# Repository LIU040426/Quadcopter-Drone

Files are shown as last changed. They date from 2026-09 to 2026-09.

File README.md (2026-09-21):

# Quadcoater Drone

## Introduction

This is a Quadcoater Drone project.

## Hardware equipment

- F450 Framework
- Turnigy Liop Battery 3S
- SKYRC LiPro Balance Charger
- AMP 2.8.0 Fly Controller
- FS-i6 Fly remote controller
- DJI 2212/920KV brushless motor and ESC *4
- GPS module 
- Battery voltage module

## Supporting equipment
- Multimeter
- Soldering tools
- Screwdriver
- Hot glue gun
- Cable tie
- 

## Soldering the Battery and ESC

Before we start this project, we need soldering the the battery line and the
ESC line to the bottom board of the F450 frame. The after soldering picture is shown below:

<div align="center">
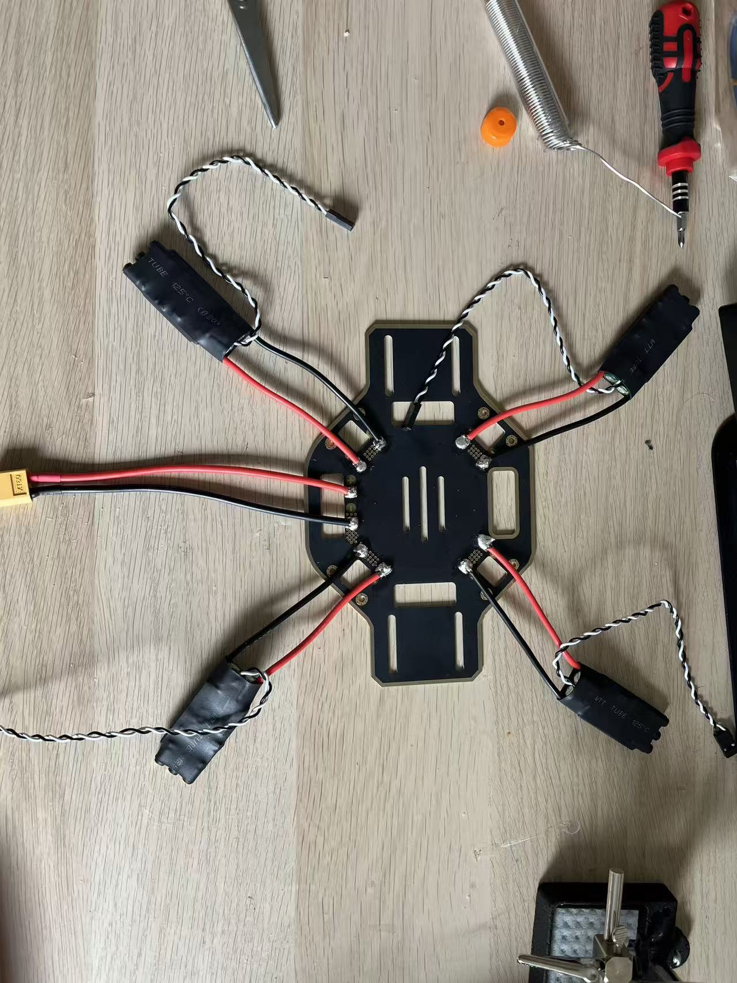
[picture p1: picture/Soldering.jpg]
  
</div>

Be Careful soldering each line in a correct pad. This F450 board has the + and - label to make sure it. After that, use the multimeter to test them.

After that, connect the battery to battery line and connect the ESC and brushless motor. It is shown below:

<div align="center">
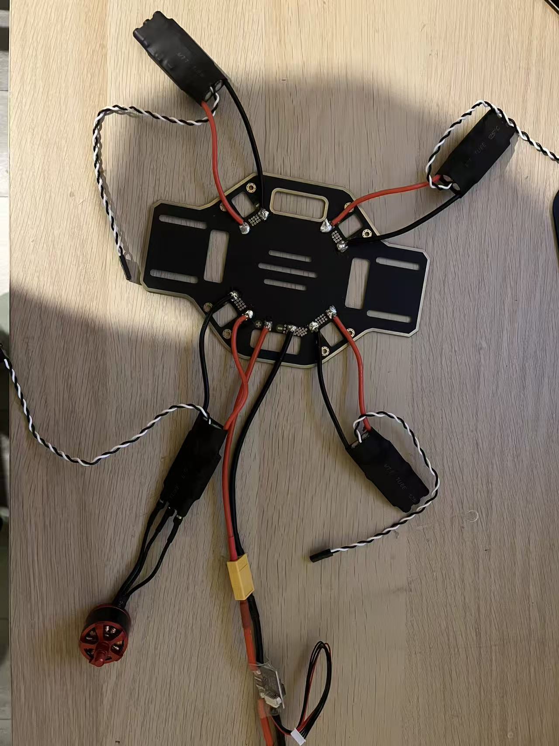
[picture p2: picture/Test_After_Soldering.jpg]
  
</div>

At this moment, the Motor will have some noise. BBBBBB...

It is normal, since the noise means the power is okay and we PWM signal input. We make sure the battery connectiong is finished well.

We can use the hot glue gun to cover the exposed solder joint we make sure it is safe and enhance the connection. This step may not essential. The picture is shown below:
<div align="center">
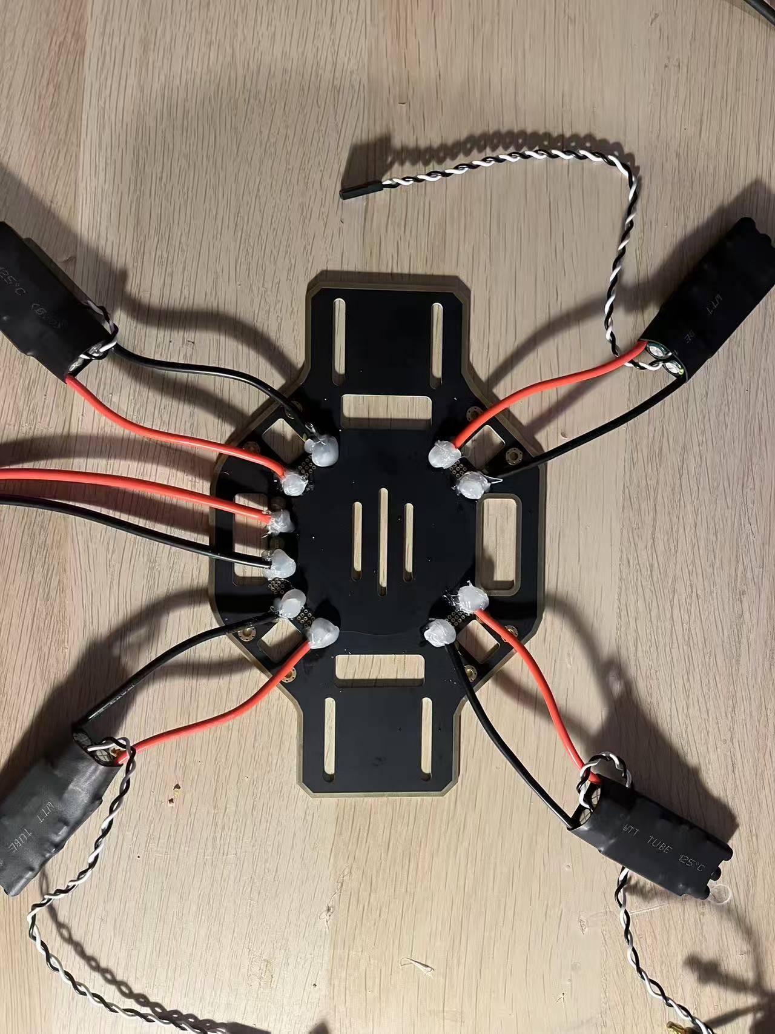
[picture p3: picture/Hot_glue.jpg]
  
</div>

After that, we can test it with multimeter again and contribute the frame.

<div align="center">
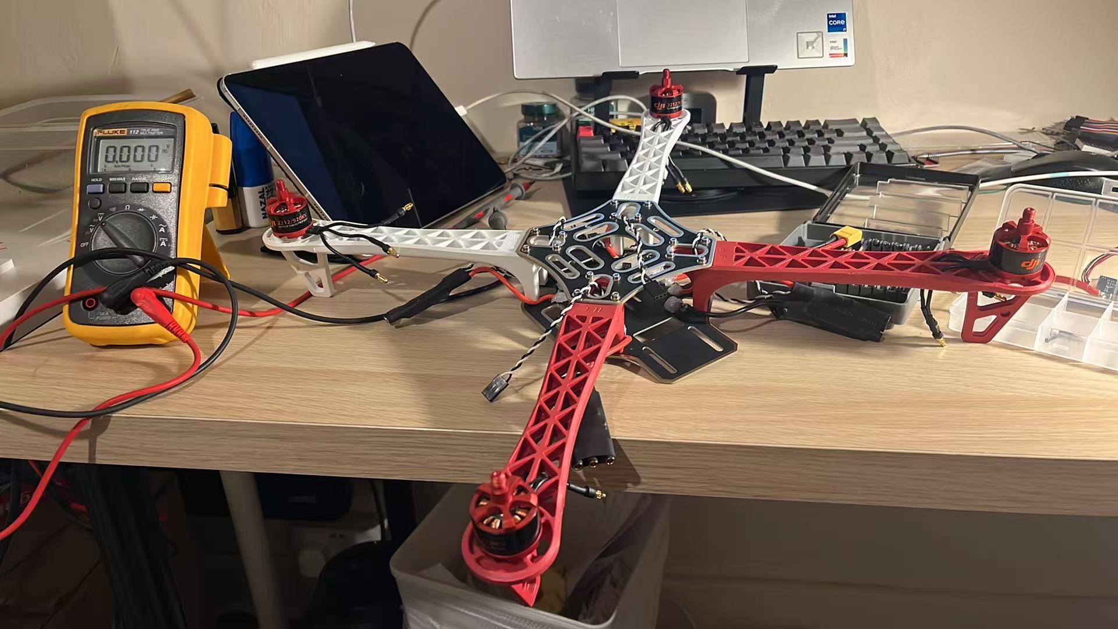
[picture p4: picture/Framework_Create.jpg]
  
</div>

## Mission Planner

The software download link is: [Mission Planner](https://ardupilot.org/planner/docs/mission-planner-installation.html)

First, connect the Fly controller and PC via Data cable. Choose the port number and bit rate.
<div align="center">
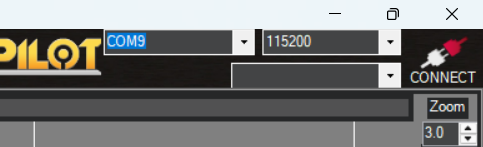
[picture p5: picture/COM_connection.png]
  
</div>

Config - Full parameter list - Reset to default
<div align="center">
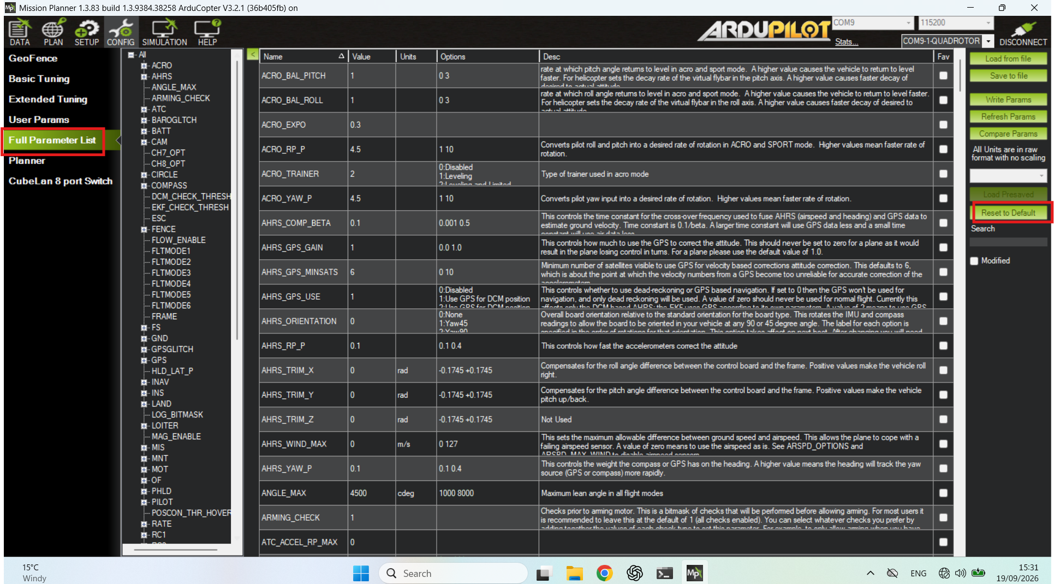
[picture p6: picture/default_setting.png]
  
</div>

And reconnect the AMP and go to the SETUP setting
<div align="center">
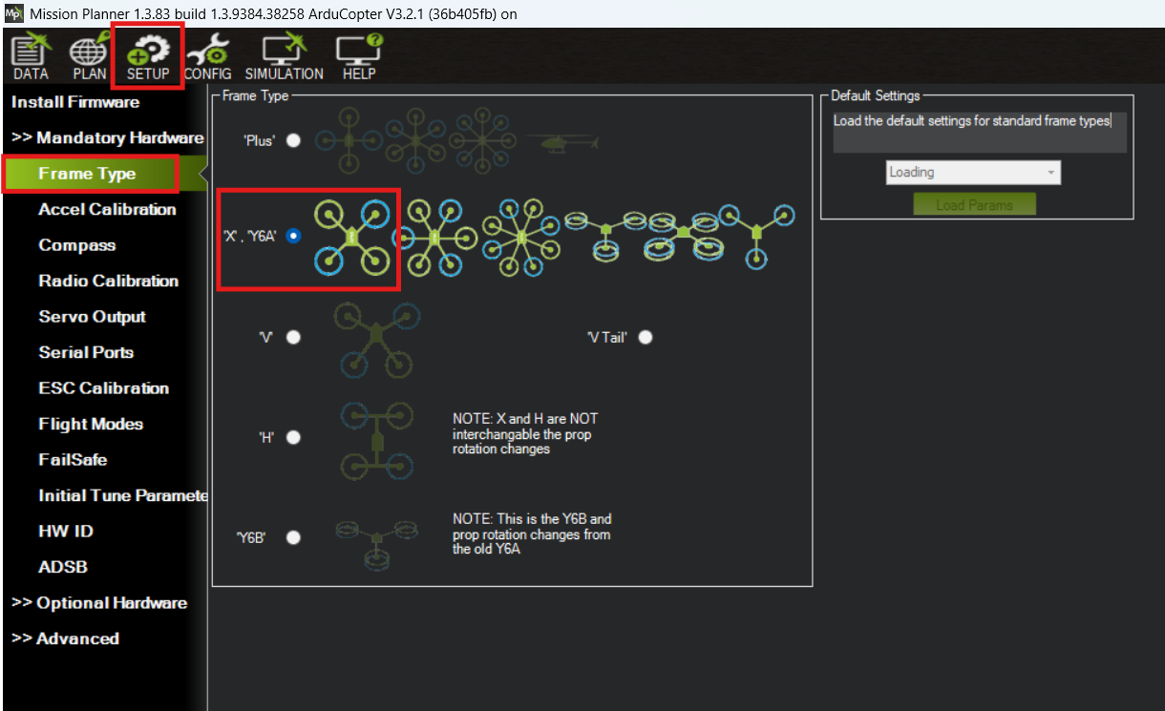
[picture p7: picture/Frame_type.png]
  
</div>

Finish the Accel_Calibration. But for the old version AMP2.8.0 the last version Mission planner 
cannot do this step. Thus, I download the 1.3.74 version for this project. Follow the step and finish it.
<div align="center">
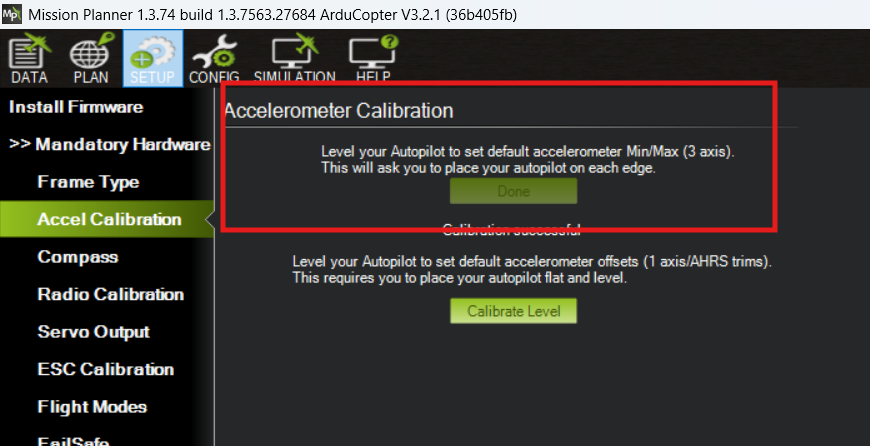
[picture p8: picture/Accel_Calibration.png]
  
</div>

Compass Calibration for the GPS module.
<div align="center">
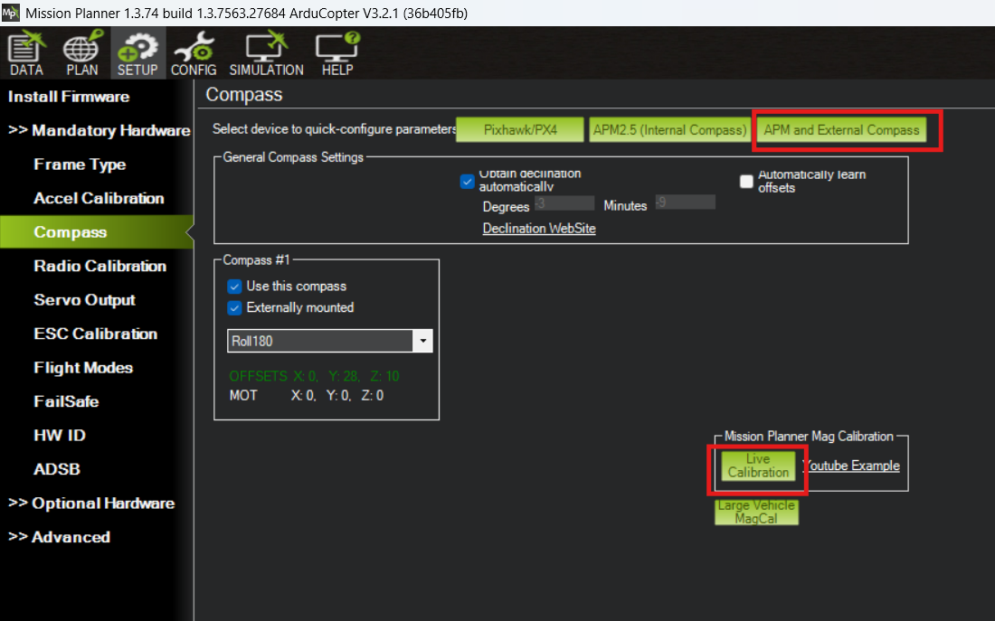
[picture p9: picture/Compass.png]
  
</div>

Radio Calibration. In this step, move the transmitter sticks through their full range of motion.
<div align="center">
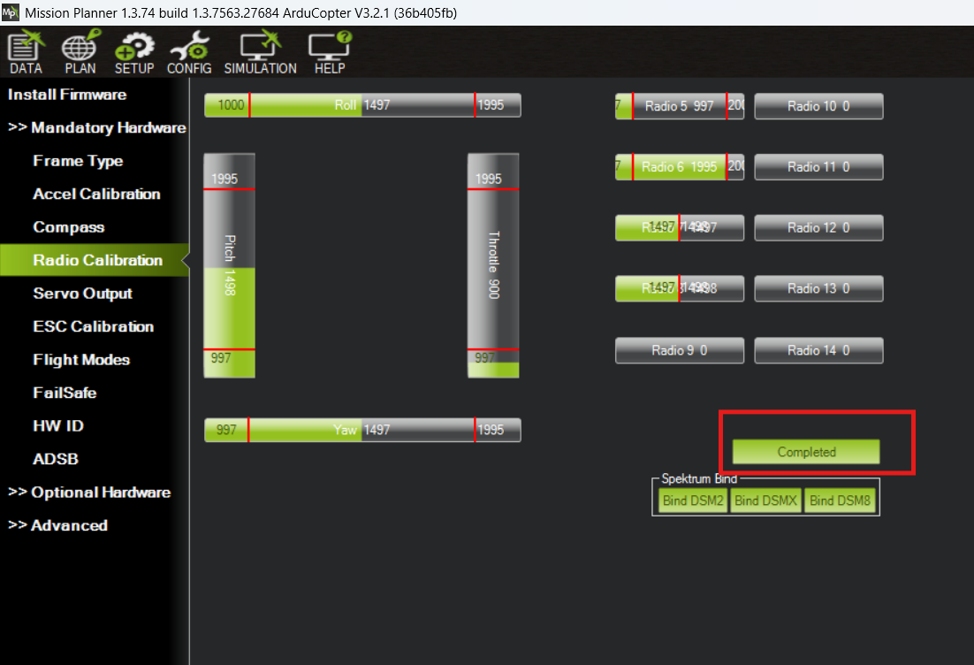
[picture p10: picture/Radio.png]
  
</div>

Set the the SWc switch for Channel 5 in transmitter.

Set the flight mode.
<div align="center">
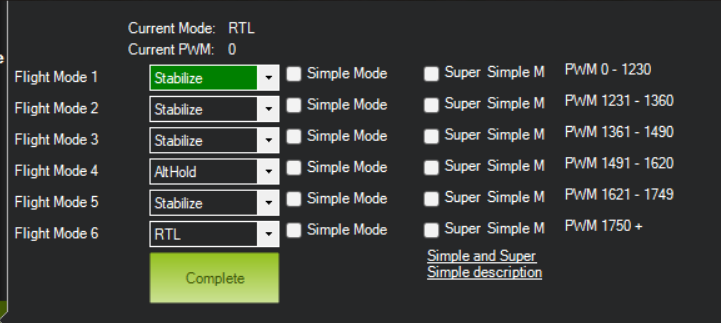
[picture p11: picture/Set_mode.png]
  
</div>

Set the battery setting.
<div align="center">
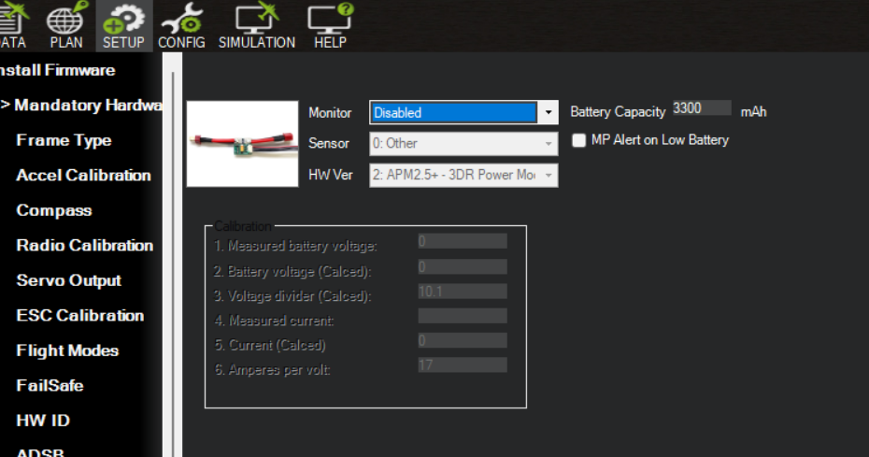
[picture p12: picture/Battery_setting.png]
  
</div>

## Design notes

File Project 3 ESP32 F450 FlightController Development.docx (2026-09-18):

Advanced Programming for Robotic

Quadcopter Development

Introduction

This project is designed for the student to participate in the multidisciplinary study of robotic technology. The project is focused on developing the engineering literacies of students, e.g., skill development, self-driven learning, and teamwork development. After the project, students will be able to:

- Apply problem-solving strategies to various technical problems that are increasing in complexity.
- Analyse different robotic programming concepts and apply them to a particular programming problem.
- Design, develop, test and document for the development of robotic applications.
- Develop applications to control sensor inputs and outputs connected to a microcontroller.

Objective

Essential

- Use the ESP32 Dev Board to develop a flight controller for the F450 quadcopter.
- Develop the 3D model for the holder of the developed ESP32-based flight controller to fit in an F450 quadcopter frame and have the 3D printed frame.

Optional

- Develop an F450 quadcopter frame and have the frame printed.
- Determine the appropriate component for the assembly of 3D printed F450 frame
- Assemble the quadcopter using the developed ESP32-Devboard-based flight controller and F450 3D printed frame.
- Complete the binding process for the Flysky remote controller and receivers and develop an operation manual for the binding process.
- Able to have the basic pilot skill of operating a quadcopter.

Self-driven learning

Understanding the motor configuration

- Numbering of the motors
- The direction of motor rotation
- Connection of motor to ESC clockwise vs anticlockwise

Understanding the connection of MPU6050 with the ESP32-Dev board

Understanding the system configuration of the typical quadcopter system.

Understanding the drone health and safety regulations.

3D modelling and 3D print development

1. Develop F450 3D model and 3D print the developed F450 Frame
2. Develop holder for ESP32-based flight controller with the MPU6050 Gyroscope

Components

- Quadcopter frame F450
- The flight controller ESP32-DevKit V1 (30 pins)
- RC Receiver Flysky FS-iA6B
- RC remote controller Flysky FS-i6
- Lipo Battery 3s Lipo Battery
- Gyro-scope MPU6050
- Propeller CW x 2, CCW x 2

ESP32-DevKit V1 Board (30 pins)

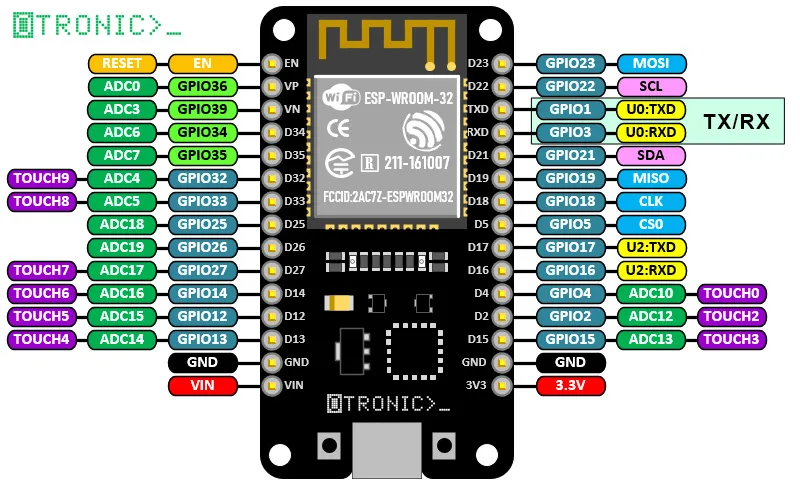
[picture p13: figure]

Reference: https://www.otronic.nl/fr/esp32-wroom-4mb-devkit-v1-avec-broches-den-tete-se.html

F450 Quadcopter Frame

The DJI F450 Quadcopter is a classic quadcopter frame standard for drone development. It could be the most popular drone frame standard for beginners in drone DIY development.

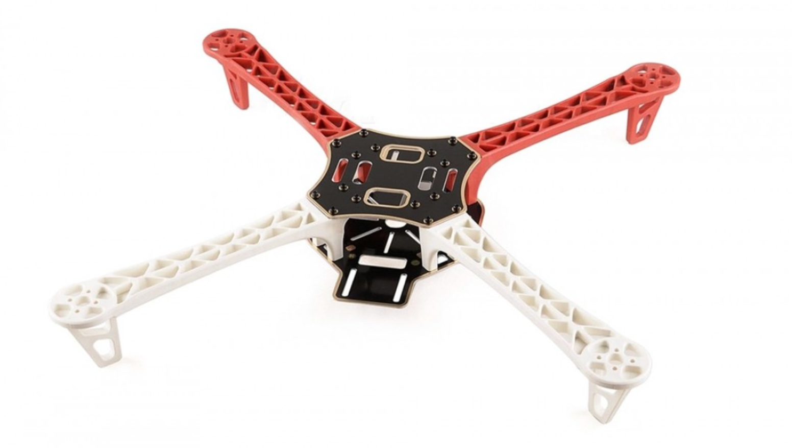
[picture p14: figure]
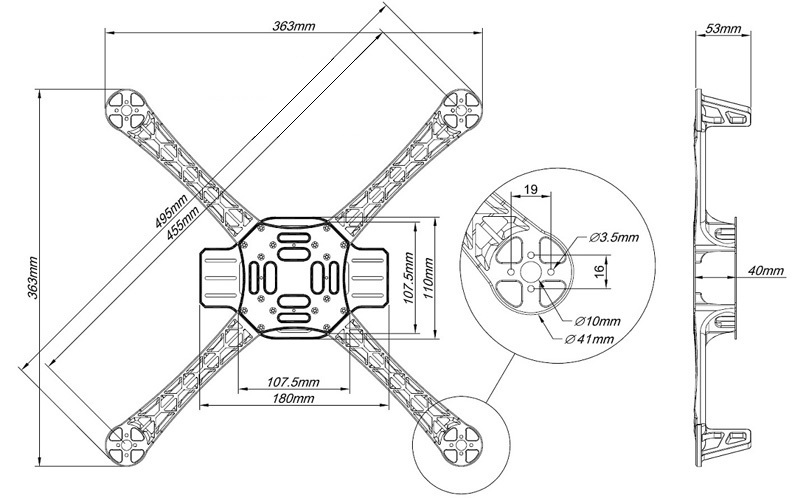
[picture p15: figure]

Reference: F450/Q450 Quadcopter frame Kit with integrated PCB (veerobot.com) (https://veerobot.com/cat-medium-frame/f450-quadcopter-frame-kit-integrated-pcb)

Reference: F450 dimensions · Large Quadcopter Build (george-hawkins.github.io) (https://george-hawkins.github.io/arf-drone/docs/f450-dimensions)

Inertial Measurement Unit (IMU) MPU6050

The MPU-60X0 is the world’s first integrated 6-axis MotionTracking device that combines a 3-axis gyroscope, 3-axis accelerometer, and a Digital Motion Processor™ (DMP) all in a small 4x4x0.9mm package. With its dedicated I2C sensor bus, it directly accepts inputs from an external 3-axis compass to provide a complete 9-axis MotionFusion™ output. The MPU-60X0 MotionTracking device, with its 6-axis integration, onboard MotionFusion™, and run-time calibration firmware, enables manufacturers to eliminate the costly and complex selection, qualification, and system level integration of discrete devices, guaranteeing optimal motion performance for consumers. The MPU-60X0 is also designed to interface with multiple non-inertial digital sensors, such as pressure sensors, on its auxiliary I2C port. The MPU-60X0 is footprint-compatible with the MPU-30X0 family.

Reference: MPU-6000 and MPU-6050 Product Specification Revision 3.4

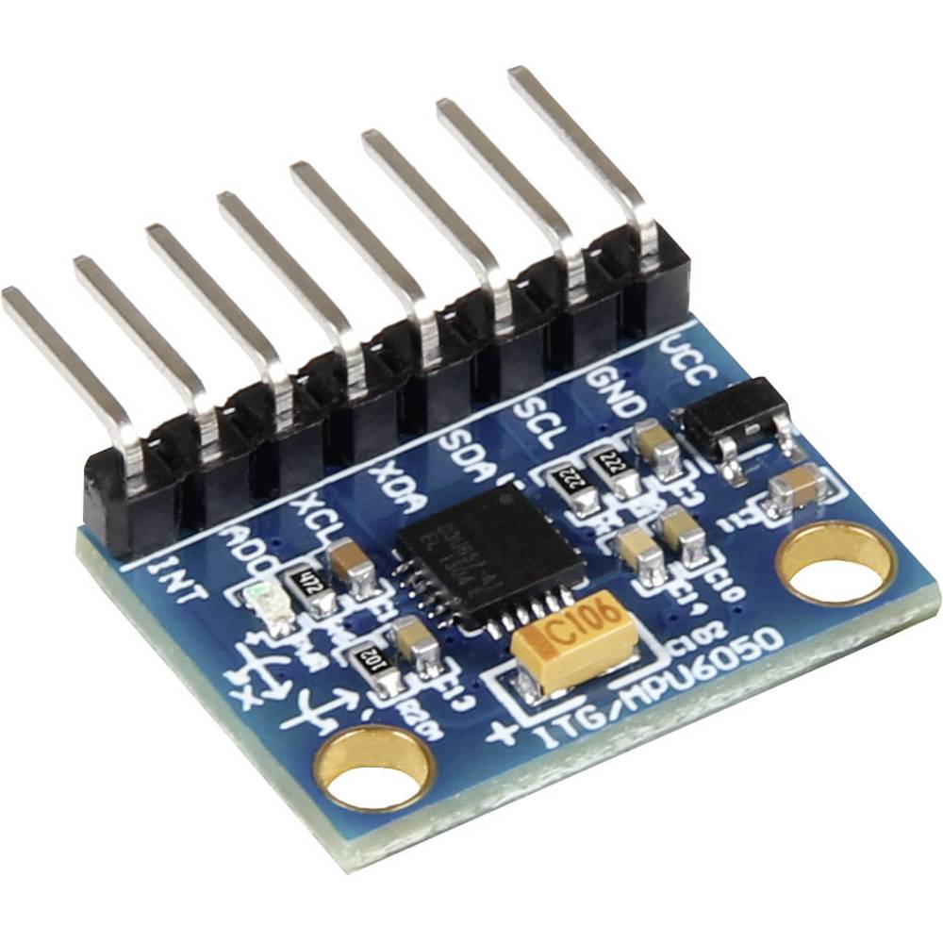
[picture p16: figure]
Joy-it MPU6050 Acceleration sensor 1 pc(s) Compatible with (development kits): BBC micro:bit, Arduino, Raspberry Pi, Roc

Figure MPU6050

Flight Controller Program Configuration

For reference information, see the project in Git Hub, ESP32-Flight-controller. Reference: https://github.com/pratikPhadte/ESP32-Flight-controller

The flight controller program can be found in GitHub, in the above link, Anglemode_flightcontroller_ver3.ino (https://github.com/pratikPhadte/ESP32-Flight-controller-/blob/main/Anglemode_flightcontroller_ver3/Anglemode_flightcontroller_ver3.ino)

To configure the program, the essential library, ESP32Servo.h, needs to be installed. Open the library manager, search the keyword ‘ESP32Servo.h’, the search result shows a library ESP32Servo by K. Harrington and J. K. Bennett. The library allows ESP32 boards to control servo.

Connection of FLYSKY FS-iA6B RC Receiver with ESP32 DevKit V1

The connection of FS-iA6B with the ESP32-DevKit-V1

FS-iA6B RC receiver | ESP320-DevKit-V1
CH1 | D34
CH2 | D35
CH3 | D32
CH4 | D33
CH5 | D25
CH6 (top pin) | D26
CH6 (middle pin) | VIN
CH6 (bottom pin) | GND

Connection of the IMU Sensor (MPU6050) via I2C connection with ESP32 DevKit V1

- The MPU6050 should place at the very centre of the quadcopter.
- Keep the MPU6050 solder line facing to the rear of the quadcopter.

Sensor Gyroscope (MPU6050) | ESP32 DevKit V1 board (30-pins) | Actual Pin Connection
SCL | I2C_CLK | Pin D22_SCL (GPIO22)
SDA | I2D_SDA | Pin D21_SDA (GPIO 21)
INT | IMU_EXIT | N/A
VCC | 3V3 | 3.3 V
GND | GND | GND

Connection of the Electronic Speed Controller (ESC) with ESP32 DevKit V1

ESC | ESP32 DevKit V1 board (30-pins) | Actual Pin Connection
Motor 1 (white cable) | GPIO 13 | D13
Motor 2 (white cable) | GPIO 12 | D12
Motor 3 (white cable) | GPIO 14 | D14
Motor 4 (white cable) | GPIO 27 | D27
GND (black cable) | GND | GND

To check either the ESC and motor are functional:

Prior to checking, the remote controller must bind with the receiver.

Connect the ESC’s signal connector to channel 3 of the FS-iA6B, which is the throttle signal.

The FS-iA6B needs to power on and connect the battery to the ESC.

If the ESC does not receive any or correct signal from the receiver (this may be because the remote controller is not turned ON), it will give constant beeping of about 1-second duration.

If the ESC receive the the correct signal from the receiver, a self-calibration sound will be given:

Definition of Motor Location and Rotation Direction

For the DJI product standard, i.e. the motor and propeller, the CW is given in Black nuts, and the CCW is given in Silver nuts.

Front
Motor ID | Location | Rotation Direction
1 | Front Right | CCW
2 | Rear Right | CW
3 | Rear Left | CCW
4 | Front Left | CW

Back

Motor rotation can switch between CW and CCW by switching any two wires' connections.

FS-i6 remote controller and FS-iA6B receiver Binding

The binding process is straightforward:

1. Insert the bind key (the wire clip usually comes with the receiver’s package) into the FS-iA6B receiver’s B/VCC channel.
2. Apply 5V and GND to any channel’s middle and bottom pins. (The 5V and GND can be obtained from the power supply unit via two male-to-female Dupo wires.)
3. After connecting the 5V and GND to the channel, the FS-iA6B receiver's LED will flash.
4. Keep pressing the bind key of the remote controller, located at the bottom left corner of the remote controller and turn on the remote controller's power.
5. The FS-iA6B receiver's LED will stop flashing and turn to constant ON, indicating that the binding is successful.

(If the process is different from the above description, it may be due to the remote controller or receiver being faulty, although it is improbable will happen.)

FS-i6 remote controller configuration

The program files for this quadcopter development project

Reference: GitHub: https://github.com/pratikPhadte/ESP32-Flight-controller-

- Angemode_flightcontroller_ver3

This is the complete code for the ESP32 flight controller, you may have to upload additional libraries in your Arduino ide. Before uploading the code in the ESP32, keep the quadcopter on a spirit-level surface, when the code is uploaded in the ESP32, Make sure to give an initial 10s calibration time for the quadcopter to calibrate Gyro, now after 2 LED blinks on the pin15 the quadcopter is ready for flight.

1. receiver_pwm_esp32 - This code is independently to test the receiver & transmitter signals on serial monitor. connect the receiver to the esp32 board as mentioned in the schematic.
2. measure_angles_mpu - IMU angle checker, connect the imu to the esp32 via the i2c protocal as mentioned in the schematic.
3. Motors calibration - The motor's ESCs have to be calibrated before the flight, such that they start simultaneously, run this code first and calibrate your ESC as per the proper procedure.
4. Voltage measurement esp32 - this code will measure the voltage level of the Lipo 11v battery, you may have to adjust the code values of the resistors as per your -actual resistor values used in the circuit.

Appendix

ESP32 Flight Controller Program

#include <Wire.h>

#include <ESP32Servo.h> // Change to the standard Servo library for ESP32

volatile float RatePitch, RateRoll, RateYaw;

volatile float RateCalibrationPitch, RateCalibrationRoll, RateCalibrationYaw;

int RateCalibrationNumber;

Servo mot1;

Servo mot2;

Servo mot3;

Servo mot4;

const int mot1_pin = 13;

const int mot2_pin = 12;

const int mot3_pin = 14;

const int mot4_pin = 27;

volatile uint32_t current_time;

volatile uint32_t last_channel_1 = 0;

volatile uint32_t last_channel_2 = 0;

volatile uint32_t last_channel_3 = 0;

volatile uint32_t last_channel_4 = 0;

volatile uint32_t last_channel_5 = 0;

volatile uint32_t last_channel_6 = 0;

volatile uint32_t timer_1;

volatile uint32_t timer_2;

volatile uint32_t timer_3;

volatile uint32_t timer_4;

volatile uint32_t timer_5;

volatile uint32_t timer_6;

volatile int ReceiverValue[6]; // Increase the array size to 6 for Channel 1 to Channel 6

const int channel_1_pin = 34;

const int channel_2_pin = 35;

const int channel_3_pin = 32;

const int channel_4_pin = 33;

const int channel_5_pin = 25;

const int channel_6_pin = 26;

// float voltage;

float DesiredRateRoll, DesiredRatePitch, DesiredRateYaw;

float ErrorRateRoll, ErrorRatePitch, ErrorRateYaw;

float InputRoll, InputThrottle, InputPitch, InputYaw;

float PrevErrorRateRoll, PrevErrorRatePitch, PrevErrorRateYaw;

float PrevItermRateRoll, PrevItermRatePitch, PrevItermRateYaw;

float PIDReturn[] = {0, 0, 0};

// float AccX, AccY, AccZ;

// float AngleRoll, AnglePitch;

// float KalmanAngleRoll=0, KalmanUncertaintyAngleRoll=2*2;

// float KalmanAnglePitch=0, KalmanUncertaintyAnglePitch=2*2;

// float Kalman1DOutput[]={0,0};

float PRateRoll = 0.75; //For outdoor flights, keep this gain to 0.75 and for indoor flights keep the gain to be 0.6

float IRateRoll = 0.012;

float DRateRoll = 0.0085;

float PRatePitch = PRateRoll;

float IRatePitch = IRateRoll;

float DRatePitch = DRateRoll;

float PRateYaw = 4.2;

float IRateYaw = 2.8;

float DRateYaw = 0;

uint32_t LoopTimer;

float t=0.006; //time cycle

//Kalman filters for angle mode

volatile float AccX, AccY, AccZ;

volatile float AngleRoll, AnglePitch;

volatile float KalmanAngleRoll=0, KalmanUncertaintyAngleRoll=2*2;

volatile float KalmanAnglePitch=0, KalmanUncertaintyAnglePitch=2*2;

volatile float Kalman1DOutput[]={0,0};

volatile float DesiredAngleRoll, DesiredAnglePitch;

volatile float ErrorAngleRoll, ErrorAnglePitch;

volatile float PrevErrorAngleRoll, PrevErrorAnglePitch;

volatile float PrevItermAngleRoll, PrevItermAnglePitch;

float PAngleRoll=2; float PAnglePitch=PAngleRoll;

float IAngleRoll=0; float IAnglePitch=IAngleRoll;

float DAngleRoll=0; float DAnglePitch=DAngleRoll;

void kalman_1d(float KalmanState, float KalmanUncertainty, float KalmanInput, float KalmanMeasurement) {

KalmanState=KalmanState + (t*KalmanInput);

KalmanUncertainty=KalmanUncertainty + (t*t*4*4); //here 4 is the vairnece of IMU i.e 4 deg/s

float KalmanGain=KalmanUncertainty * 1/(1*KalmanUncertainty + 3 * 3); //std deviation of error is 3 deg

KalmanState=KalmanState+KalmanGain * (KalmanMeasurement-KalmanState);

KalmanUncertainty=(1-KalmanGain) * KalmanUncertainty;

Kalman1DOutput[0]=KalmanState;

Kalman1DOutput[1]=KalmanUncertainty;

}

volatile float MotorInput1, MotorInput2, MotorInput3, MotorInput4;

void channelInterruptHandler()

{

current_time = micros();

// Channel 1

if (digitalRead(channel_1_pin))

{

if (last_channel_1 == 0)

{

last_channel_1 = 1;

timer_1 = current_time;

}

}

else if (last_channel_1 == 1)

{

last_channel_1 = 0;

ReceiverValue[0] = current_time - timer_1;

}

// Channel 2

if (digitalRead(channel_2_pin))

{

if (last_channel_2 == 0)

{

last_channel_2 = 1;

timer_2 = current_time;

}

}

else if (last_channel_2 == 1)

{

last_channel_2 = 0;

ReceiverValue[1] = current_time - timer_2;

}

// Channel 3

if (digitalRead(channel_3_pin))

{

if (last_channel_3 == 0)

{

last_channel_3 = 1;

timer_3 = current_time;

}

}

else if (last_channel_3 == 1)

{

last_channel_3 = 0;

ReceiverValue[2] = current_time - timer_3;

}

// Channel 4

if (digitalRead(channel_4_pin))

{

if (last_channel_4 == 0)

{

last_channel_4 = 1;

timer_4 = current_time;

}

}

else if (last_channel_4 == 1)

{

last_channel_4 = 0;

ReceiverValue[3] = current_time - timer_4;

}

// Channel 5

if (digitalRead(channel_5_pin))

{

if (last_channel_5 == 0)

{

last_channel_5 = 1;

timer_5 = current_time;

}

}

else if (last_channel_5 == 1)

{

last_channel_5 = 0;

ReceiverValue[4] = current_time - timer_5;

}

// Channel 6

if (digitalRead(channel_6_pin))

{

if (last_channel_6 == 0)

{

last_channel_6 = 1;

timer_6 = current_time;

}

}

else if (last_channel_6 == 1)

{

last_channel_6 = 0;

ReceiverValue[5] = current_time - timer_6;

}

}

void neutralPositionAdjustment()

{

int min = 1490;

int max = 1510;

if (ReceiverValue[0] < max && ReceiverValue[0] > min)

{

ReceiverValue[0]= 1500;

}

if (ReceiverValue[1] < max && ReceiverValue[1] > min)

{

ReceiverValue[1]= 1500;

}

if (ReceiverValue[3] < max && ReceiverValue[3] > min)

{

ReceiverValue[3]= 1500;

}

if(ReceiverValue[0]==ReceiverValue[1] && ReceiverValue[1]==ReceiverValue[3] && ReceiverValue[3]==ReceiverValue[0] )

{

ReceiverValue[0]= 1500;

ReceiverValue[1]= 1500;

ReceiverValue[3]= 1500;

}

}

void gyro_signals(void)

{

Wire.beginTransmission(0x68);

Wire.write(0x1A);

Wire.write(0x05);

Wire.endTransmission();

Wire.beginTransmission(0x68);

Wire.write(0x1C);

Wire.write(0x10);

Wire.endTransmission();

Wire.beginTransmission(0x68);

Wire.write(0x3B);

Wire.endTransmission();

Wire.requestFrom(0x68,6);

int16_t AccXLSB = Wire.read() << 8 | Wire.read();

int16_t AccYLSB = Wire.read() << 8 | Wire.read();

int16_t AccZLSB = Wire.read() << 8 | Wire.read();

Wire.beginTransmission(0x68);

Wire.write(0x1B);

Wire.write(0x8);

Wire.endTransmission();

Wire.beginTransmission(0x68);

Wire.write(0x43);

Wire.endTransmission();

Wire.requestFrom(0x68,6);

int16_t GyroX=Wire.read()<<8 | Wire.read();

int16_t GyroY=Wire.read()<<8 | Wire.read();

int16_t GyroZ=Wire.read()<<8 | Wire.read();

RateRoll=(float)GyroX/65.5;

RatePitch=(float)GyroY/65.5;

RateYaw=(float)GyroZ/65.5;

AccX=(float)AccXLSB/4096;

AccY=(float)AccYLSB/4096;

AccZ=(float)AccZLSB/4096;

AccZ=AccZ-0.26; // calibration offset

AngleRoll=atan(AccY/sqrt(AccX*AccX+AccZ*AccZ))*1/(3.142/180);

AnglePitch=-atan(AccX/sqrt(AccY*AccY+AccZ*AccZ))*1/(3.142/180);

}

void pid_equation(float Error, float P, float I, float D, float PrevError, float PrevIterm)

{

float Pterm = P * Error;

float Iterm = PrevIterm +( I * (Error + PrevError) * (t/2));

if (Iterm > 400)

{

Iterm = 400;

}

else if (Iterm < -400)

{

Iterm = -400;

}

float Dterm = D *( (Error - PrevError)/t);

float PIDOutput = Pterm + Iterm + Dterm;

if (PIDOutput > 400)

{

PIDOutput = 400;

}

else if (PIDOutput < -400)

{

PIDOutput = -400;

}

PIDReturn[0] = PIDOutput;

PIDReturn[1] = Error;

PIDReturn[2] = Iterm;

}

void reset_pid(void)

{

PrevErrorRateRoll=0; PrevErrorRatePitch=0; PrevErrorRateYaw=0;

PrevItermRateRoll=0; PrevItermRatePitch=0; PrevItermRateYaw=0;

PrevErrorAngleRoll=0; PrevErrorAnglePitch=0;

PrevItermAngleRoll=0; PrevItermAnglePitch=0;

}

void setup(void) {

Serial.begin(115200);

int led_time=100;

pinMode(15, OUTPUT);

digitalWrite(15, LOW);

delay(led_time);

digitalWrite(15, HIGH);

delay(led_time);

digitalWrite(15, LOW);

delay(led_time);

digitalWrite(15, HIGH);

delay(led_time);

digitalWrite(15, LOW);

delay(led_time);

digitalWrite(15, HIGH);

delay(led_time);

digitalWrite(15, LOW);

delay(led_time);

digitalWrite(15, HIGH);

delay(led_time);

digitalWrite(15, LOW);

delay(led_time);

pinMode(channel_1_pin, INPUT_PULLUP);

pinMode(channel_2_pin, INPUT_PULLUP);

pinMode(channel_3_pin, INPUT_PULLUP);

pinMode(channel_4_pin, INPUT_PULLUP);

pinMode(channel_5_pin, INPUT_PULLUP);

pinMode(channel_6_pin, INPUT_PULLUP);

attachInterrupt(digitalPinToInterrupt(channel_1_pin), channelInterruptHandler, CHANGE);

attachInterrupt(digitalPinToInterrupt(channel_2_pin), channelInterruptHandler, CHANGE);

attachInterrupt(digitalPinToInterrupt(channel_3_pin), channelInterruptHandler, CHANGE);

attachInterrupt(digitalPinToInterrupt(channel_4_pin), channelInterruptHandler, CHANGE);

attachInterrupt(digitalPinToInterrupt(channel_5_pin), channelInterruptHandler, CHANGE);

attachInterrupt(digitalPinToInterrupt(channel_6_pin), channelInterruptHandler, CHANGE);

Wire.setClock(400000);

Wire.begin();

delay(250);

Wire.beginTransmission(0x68);

Wire.write(0x6B);

Wire.write(0x00);

Wire.endTransmission();

mot1.attach(mot1_pin,1000,2000);

mot2.attach(mot2_pin,1000,2000);

mot3.attach(mot3_pin,1000,2000);

mot4.attach(mot4_pin,1000,2000);

//to stop esc from beeping

mot1.write(0);

mot2.write(0);

mot3.write(0);

mot4.write(0);

digitalWrite(15, LOW);

digitalWrite(15, HIGH);

delay(2000);

digitalWrite(15, LOW);

delay(2000);

for (RateCalibrationNumber = 0; RateCalibrationNumber < 4000; RateCalibrationNumber++)

{

gyro_signals();

RateCalibrationRoll += RateRoll;

RateCalibrationPitch += RatePitch;

RateCalibrationYaw += RateYaw;

delay(1);

}

RateCalibrationRoll /= 4000;

RateCalibrationPitch /= 4000;

RateCalibrationYaw /= 4000;

//Gyro Calibrated Values

// Serial.print("Gyro Calib: ");

// Serial.print(RateCalibrationRoll);

// Serial.print(" ");

// Serial.print(RateCalibrationPitch);

// Serial.print(" ");

// Serial.print(RateCalibrationYaw);

// Serial.print(" -- ");

digitalWrite(15, HIGH);

delay(1000);

digitalWrite(15, LOW);

delay(1000);

digitalWrite(15, HIGH);

delay(1000);

digitalWrite(15, LOW);

delay(1000);

LoopTimer = micros();

}

void loop(void) {

//enter your loop code here

gyro_signals();

RateRoll -= RateCalibrationRoll;

RatePitch -= RateCalibrationPitch;

RateYaw -= RateCalibrationYaw;

kalman_1d(KalmanAngleRoll, KalmanUncertaintyAngleRoll, RateRoll, AngleRoll);

KalmanAngleRoll=Kalman1DOutput[0]; KalmanUncertaintyAngleRoll=Kalman1DOutput[1];

kalman_1d(KalmanAnglePitch, KalmanUncertaintyAnglePitch, RatePitch, AnglePitch);

KalmanAnglePitch=Kalman1DOutput[0]; KalmanUncertaintyAnglePitch=Kalman1DOutput[1];

channelInterruptHandler();

neutralPositionAdjustment();

DesiredAngleRoll=0.1*(ReceiverValue[0]-1500);

DesiredAnglePitch=0.1*(ReceiverValue[1]-1500);

InputThrottle=ReceiverValue[2];

DesiredRateYaw=0.15*(ReceiverValue[3]-1500);

ErrorAngleRoll=DesiredAngleRoll-KalmanAngleRoll;

ErrorAnglePitch=DesiredAnglePitch-KalmanAnglePitch;

pid_equation(ErrorAngleRoll, PAngleRoll, IAngleRoll, DAngleRoll, PrevErrorAngleRoll, PrevItermAngleRoll);

DesiredRateRoll=PIDReturn[0];

PrevErrorAngleRoll=PIDReturn[1];

PrevItermAngleRoll=PIDReturn[2];

pid_equation(ErrorAnglePitch, PAnglePitch, IAnglePitch, DAnglePitch, PrevErrorAnglePitch, PrevItermAnglePitch);

DesiredRatePitch=PIDReturn[0];

PrevErrorAnglePitch=PIDReturn[1];

PrevItermAnglePitch=PIDReturn[2];

ErrorRateRoll=DesiredRateRoll-RateRoll;

ErrorRatePitch=DesiredRatePitch-RatePitch;

ErrorRateYaw=DesiredRateYaw-RateYaw;

pid_equation(ErrorRateRoll, PRateRoll, IRateRoll, DRateRoll, PrevErrorRateRoll, PrevItermRateRoll);

InputRoll=PIDReturn[0];

PrevErrorRateRoll=PIDReturn[1];

PrevItermRateRoll=PIDReturn[2];

pid_equation(ErrorRatePitch, PRatePitch,IRatePitch, DRatePitch, PrevErrorRatePitch, PrevItermRatePitch);

InputPitch=PIDReturn[0];

PrevErrorRatePitch=PIDReturn[1];

PrevItermRatePitch=PIDReturn[2];

pid_equation(ErrorRateYaw, PRateYaw,IRateYaw, DRateYaw, PrevErrorRateYaw, PrevItermRateYaw);

InputYaw=PIDReturn[0];

PrevErrorRateYaw=PIDReturn[1];

PrevItermRateYaw=PIDReturn[2];

if (InputThrottle > 1800)

{

InputThrottle = 1800;

}

MotorInput1 = (InputThrottle - InputRoll - InputPitch - InputYaw); // front right - counter clockwise

MotorInput2 = (InputThrottle - InputRoll + InputPitch + InputYaw); // rear right - clockwise

MotorInput3 = (InputThrottle + InputRoll + InputPitch - InputYaw); // rear left - counter clockwise

MotorInput4 = (InputThrottle + InputRoll - InputPitch + InputYaw); //front left - clockwise

if (MotorInput1 > 2000)

{

MotorInput1 = 1999;

}

if (MotorInput2 > 2000)

{

MotorInput2 = 1999;

}

if (MotorInput3 > 2000)

{

MotorInput3 = 1999;

}

if (MotorInput4 > 2000)

{

MotorInput4 = 1999;

}

int ThrottleIdle = 1150;

if (MotorInput1 < ThrottleIdle)

{

MotorInput1 = ThrottleIdle;

}

if (MotorInput2 < ThrottleIdle)

{

MotorInput2 = ThrottleIdle;

}

if (MotorInput3 < ThrottleIdle)

{

MotorInput3 = ThrottleIdle;

}

if (MotorInput4 < ThrottleIdle)

{

MotorInput4 = ThrottleIdle;

}

int ThrottleCutOff = 1000;

if (ReceiverValue[2] < 1050)

{

MotorInput1 = ThrottleCutOff;

MotorInput2 = ThrottleCutOff;

MotorInput3 = ThrottleCutOff;

MotorInput4 = ThrottleCutOff;

reset_pid();

}

mot1.write(map(MotorInput1, 1000, 2000, 0, 180));

mot2.write(map(MotorInput2, 1000, 2000, 0, 180));

mot3.write(map(MotorInput3, 1000, 2000, 0, 180));

mot4.write(map(MotorInput4, 1000, 2000, 0, 180));

// voltage= (analogRead(36)/4096)*12.46*(35.9/36);

// if(voltage<11.1)

// {

// }

//Reciever signals

// Serial.print(ReceiverValue[0]);

// Serial.print(" - ");

// Serial.print(ReceiverValue[1]);

// Serial.print(" - ");

// Serial.print(ReceiverValue[2]);

// Serial.print(" - ");

// Serial.print(ReceiverValue[3]);

// Serial.print(" --- ");

// // Serial.print(ReceiverValue[4]);

// // Serial.print(" - ");

// // Serial.print(ReceiverValue[5]);

// // Serial.print(" - ");

//Motor PWMs in us

// Serial.print("MotVals-");

// Serial.print(MotorInput1);

// Serial.print(" ");

// Serial.print(MotorInput2);

// Serial.print(" ");

// Serial.print(MotorInput3);

// Serial.print(" ");

// Serial.print(MotorInput4);

// Serial.print(" -- ");

// //Reciever translated rates

// Serial.print(DesiredRateRoll);

// Serial.print(" ");

// Serial.print(DesiredRatePitch);

// Serial.print(" ");

// Serial.print(DesiredRateYaw);

// Serial.print(" -- ");

// //Gyro Rates

// Serial.print(" Gyro rates:");

// Serial.print(RateRoll);

// Serial.print(" ");

// Serial.print(RatePitch);

// Serial.print(" ");

// Serial.print(RateYaw);

// Serial.print(" -- ");

//PID outputs

// Serial.print("PID O/P ");

// Serial.print(InputPitch);

// Serial.print(" ");

// Serial.print(InputRoll);

// Serial.print(" ");

// Serial.print(InputYaw);

// Serial.print(" -- ");

//Angles from MPU

// Serial.print("AngleRoll:");

// Serial.print(AngleRoll);

// //serial.print(" ");

// Serial.print("AnglePitch:");

// Serial.println(AnglePitch);

// Serial.println(" ");

while (micros() - LoopTimer < (t*1000000));

{

LoopTimer = micros();

}

}

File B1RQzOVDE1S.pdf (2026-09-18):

Pg1

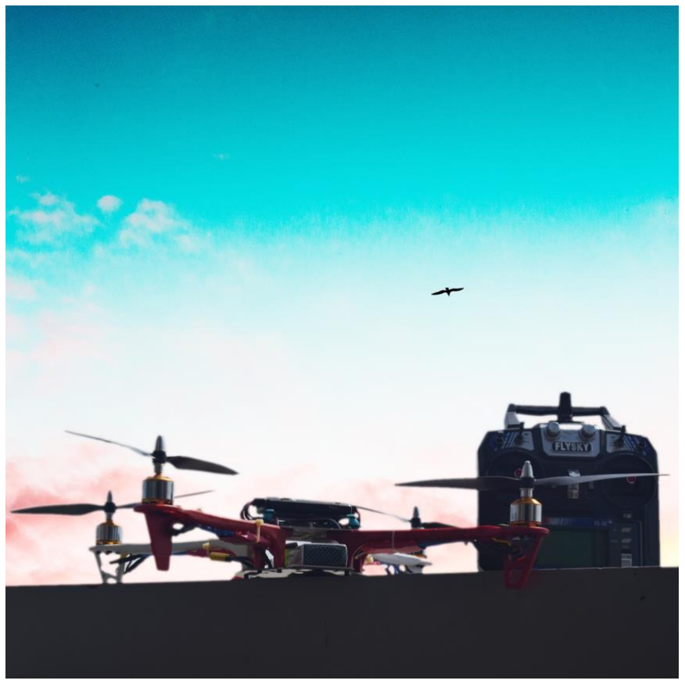
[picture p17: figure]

Pg
2
- Quadcopter Frame – 1 set
- Jumper Wire (Female to Female) – 8 sets
- FlySky FS-i6 2.4G 6CH AFHDS RC Transmitter – 1
- Fly Sky FS-iA6 Receiver – 1
- Propellers - 2 sets
- 1400 Kv Brushless Motor – 4
- Propellers nuts and screws – 2 sets
- 3500 mAh Lipo Battery with XT60 Female Connector – 1

Hardware Required

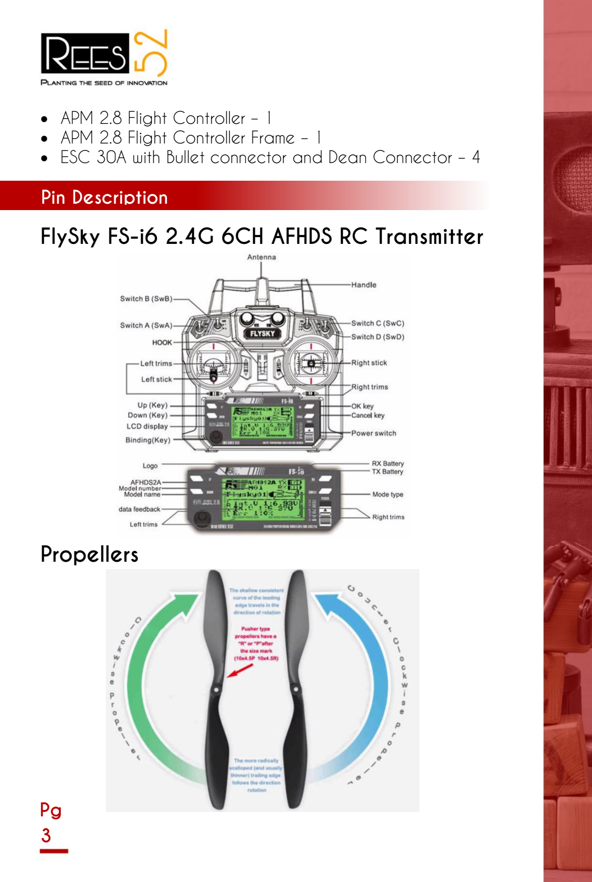
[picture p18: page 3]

Pg
3
- APM 2.8 Flight Controller – 1
- APM 2.8 Flight Controller Frame – 1
- ESC 30A with Bullet connector and Dean Connector – 4

### FlySky FS-i6 2.4G 6CH AFHDS RC Transmitter

### Propellers

Pin Description

### 1400 Kv Brushless Motor

Pg
4

### APM 2.8 Flight Controller

Pg
5

### ESC 30A with Bullet Connector and Dean Connector

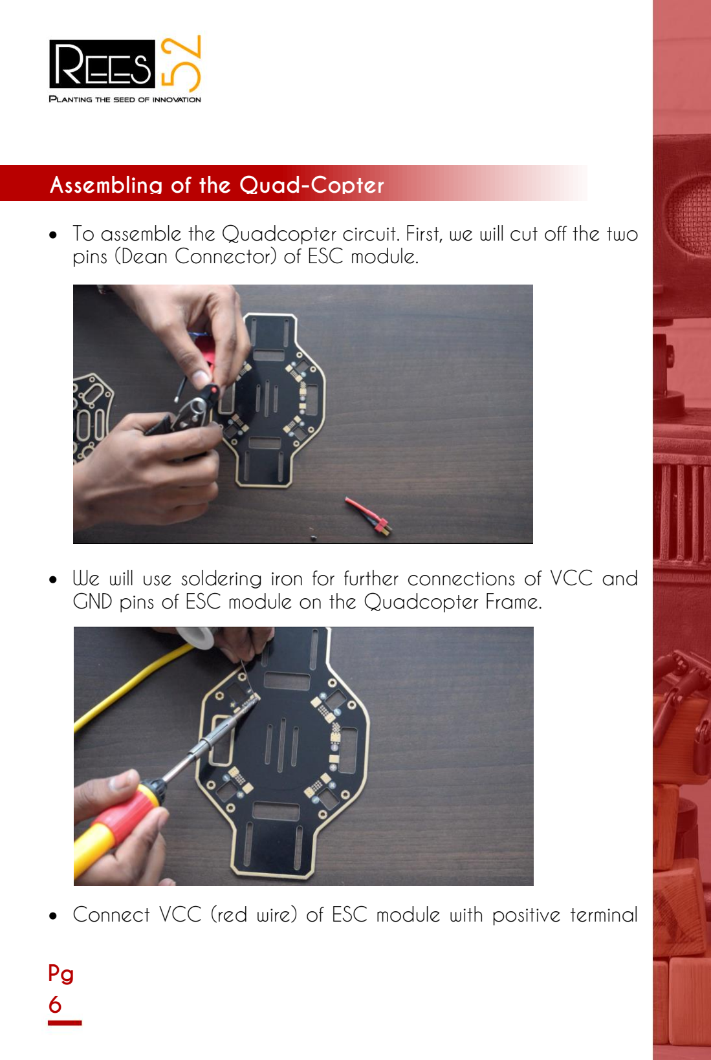
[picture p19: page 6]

Pg
6
- To assemble the Quadcopter circuit. First, we will cut off the two pins (Dean Connector) of ESC module.
- We will use soldering iron for further connections of VCC and GND pins of ESC module on the Quadcopter Frame.
- Connect VCC (red wire) of ESC module with positive terminal

Assembling of the Quad-Copter

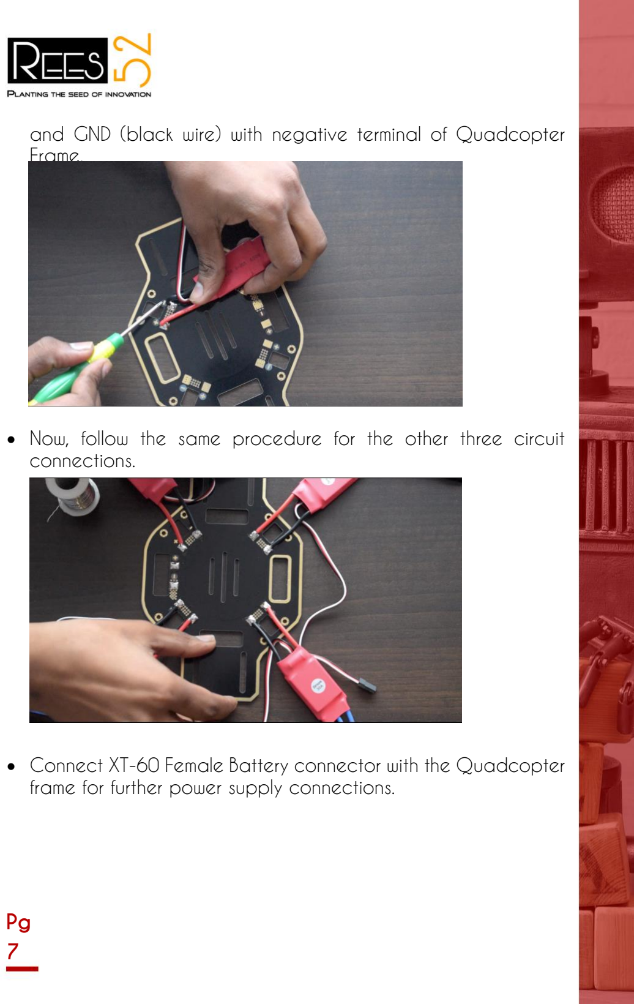
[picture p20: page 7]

Pg
7

and GND (black wire) with negative terminal of Quadcopter Frame.

- Now, follow the same procedure for the other three circuit connections.
- Connect XT-60 Female Battery connector with the Quadcopter frame for further power supply connections.

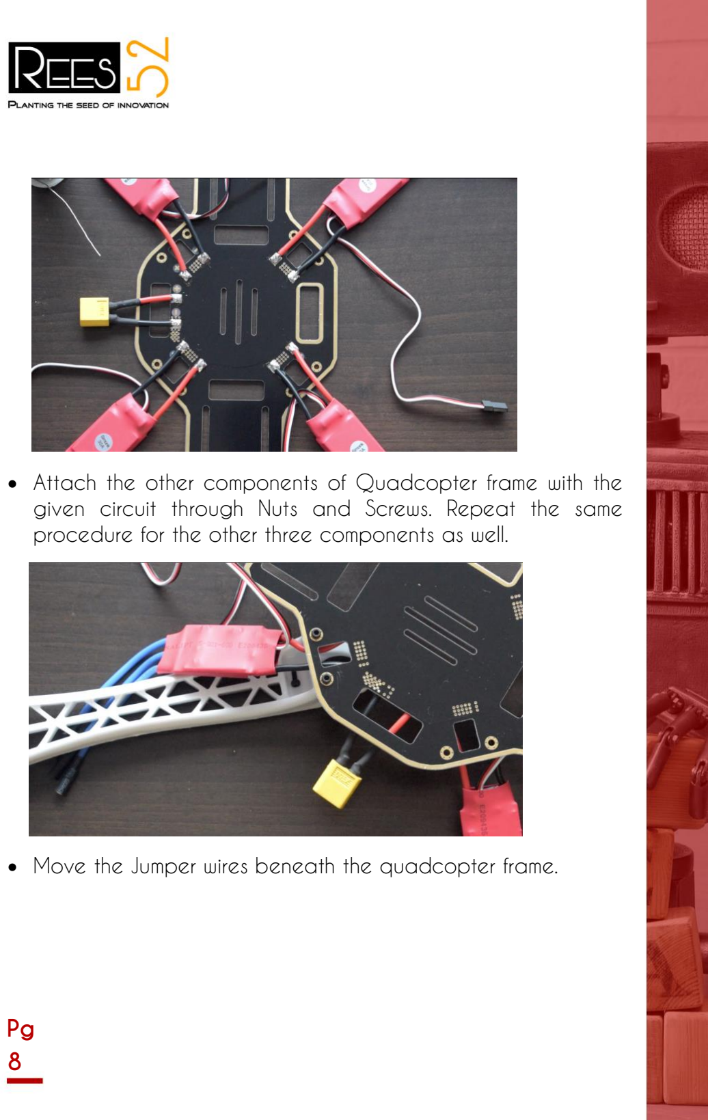
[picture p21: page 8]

Pg
8
- Attach the other components of Quadcopter frame with the given circuit through Nuts and Screws. Repeat the same procedure for the other three components as well.
- Move the Jumper wires beneath the quadcopter frame.

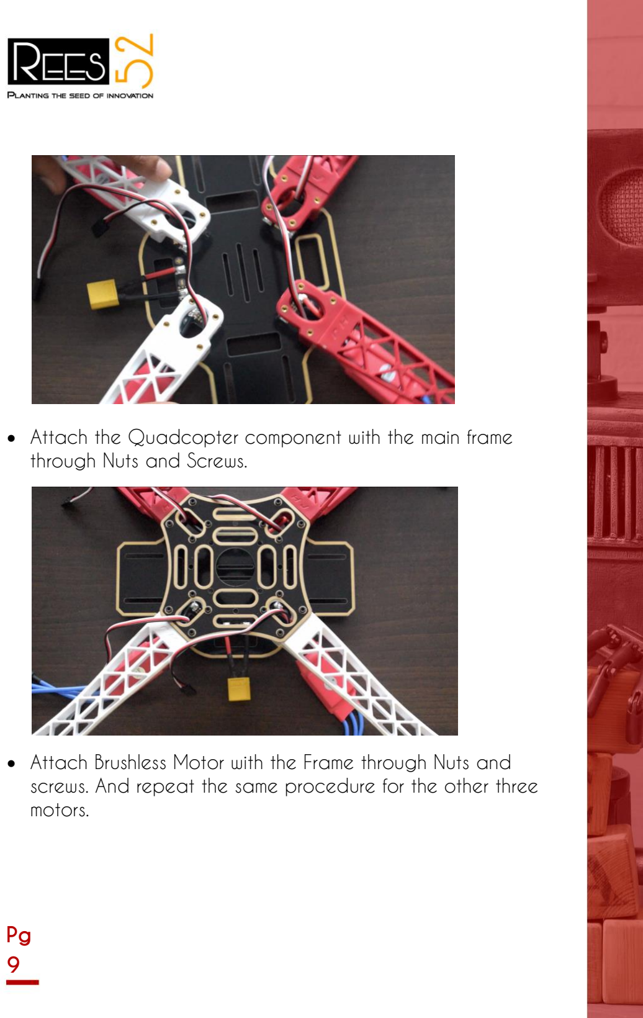
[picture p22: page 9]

Pg
9
- Attach the Quadcopter component with the main frame through Nuts and Screws.
- Attach Brushless Motor with the Frame through Nuts and screws. And repeat the same procedure for the other three motors.

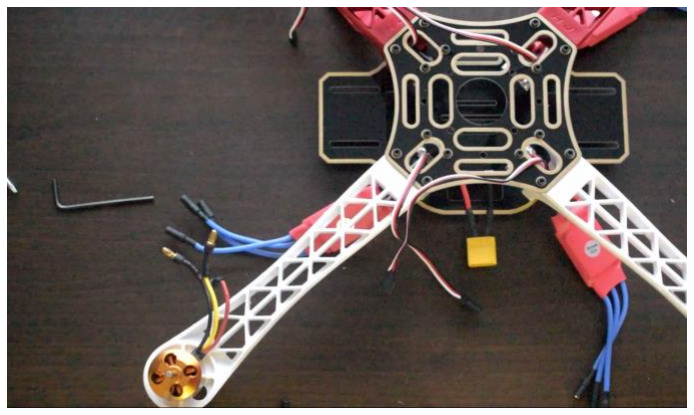
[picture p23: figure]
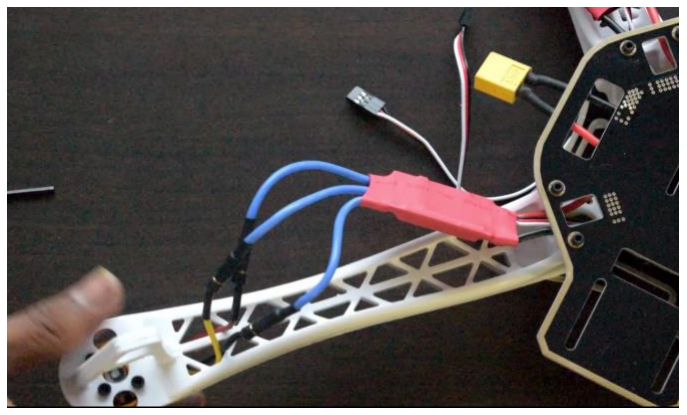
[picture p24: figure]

Pg
10
- Now, we’ll do the ESC connections as follows:
- Connect the VCC of ESC with VCC of motor.
- Connect the GND of ESC with GND of motor.
- Connect the PWM/Signal of ESC with Signal of motor. And repeat the same step for front facing motor.
- Now, we’ll do the ESC connections as follows:
- Connect the VCC of ESC with VCC of motor.

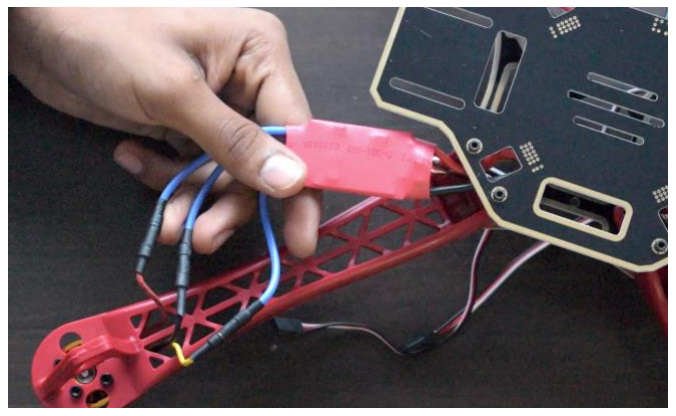
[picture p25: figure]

Pg
11
- Connect the GND of ESC with Signal/PWM of motor.
- Connect the PWM/Signal of ESC with GND of motor. And repeat the same step for front facing motor.
- Place Ardupilot Flight Controller over the Frame.
- Assemble the frame for Ardupilot Flight Controller.

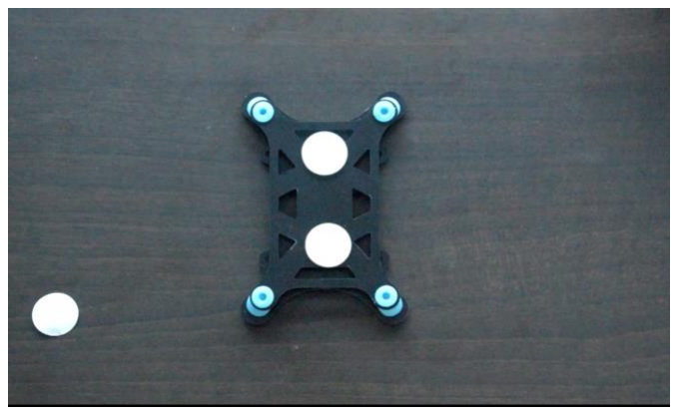
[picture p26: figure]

Pg
12
- Place and attach Ardupilot Flight Controller over the Quadcopter Frame through double sided tape.
- Connect Ardupilot Input Pins 1-5 with the Fly Sky FS-iA6 Receiver Channel Input Pins CH1-CH5 via Jumper wires (Female to Female)

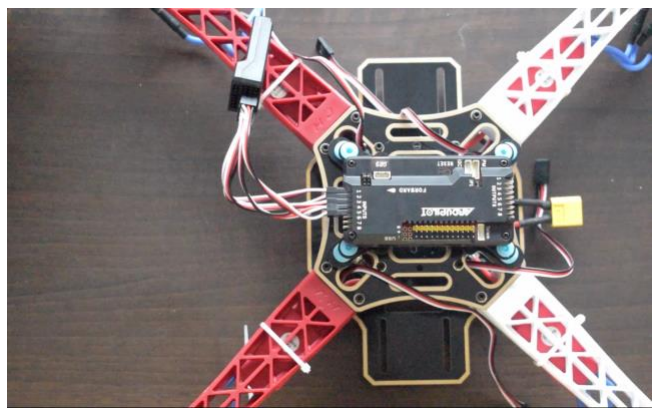
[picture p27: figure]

Pg
13
- Now, place and attach Fly Sky FS-iA6 Receiver and Jumper wires over the Quadcopter frame via cable ties.
- Attach the Receiver Pins with the quadcopter frame via cable ties.

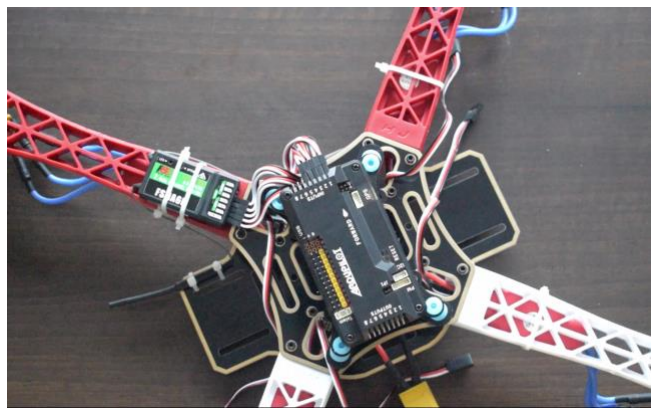
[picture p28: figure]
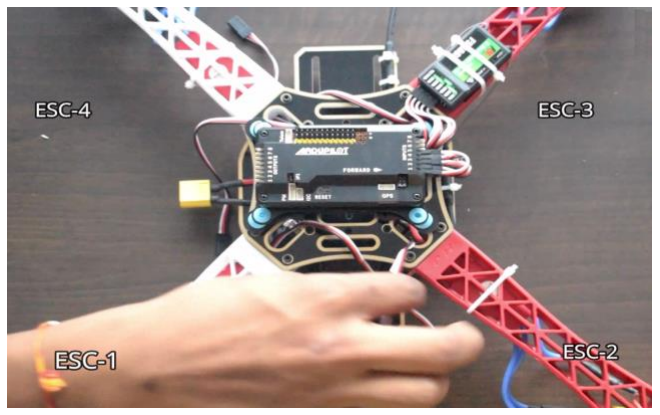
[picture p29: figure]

Pg
14
- Here are the given ESC of the Quadcopter Frame.
- Now, we’ll do the ESC connections with Ardupilot Flight Controller as follows:
- Connect the ESC-2 Pin with Ardupilot Output Pin - 1.
- Connect the ESC-4 Pin with Ardupilot Output Pin - 2.
- Connect the ESC-3 Pin with Ardupilot Output Pin - 3.
- Connect the ESC-1 Pin with Ardupilot Output Pin - 4.

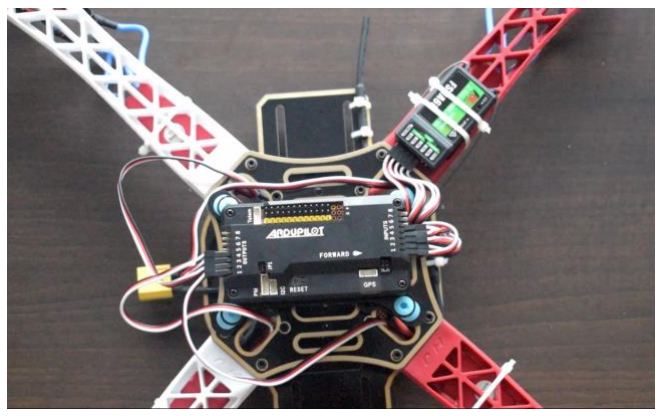
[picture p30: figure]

Pg
15
- Attach adapter, back plate with the motor to connect propeller.
- And then attach spinner cap above the propeller. Repeat the same procedure for the other three propellers.

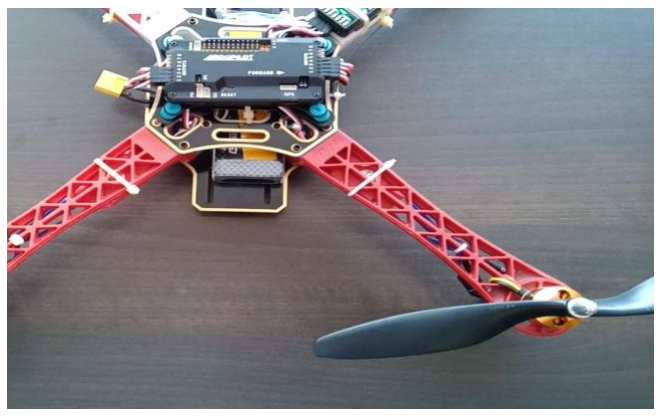
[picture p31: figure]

Pg
16
- Install Mission Planner Software.
- Go to the Option Flight Planner and connect Quadcopter with System via USB cable.

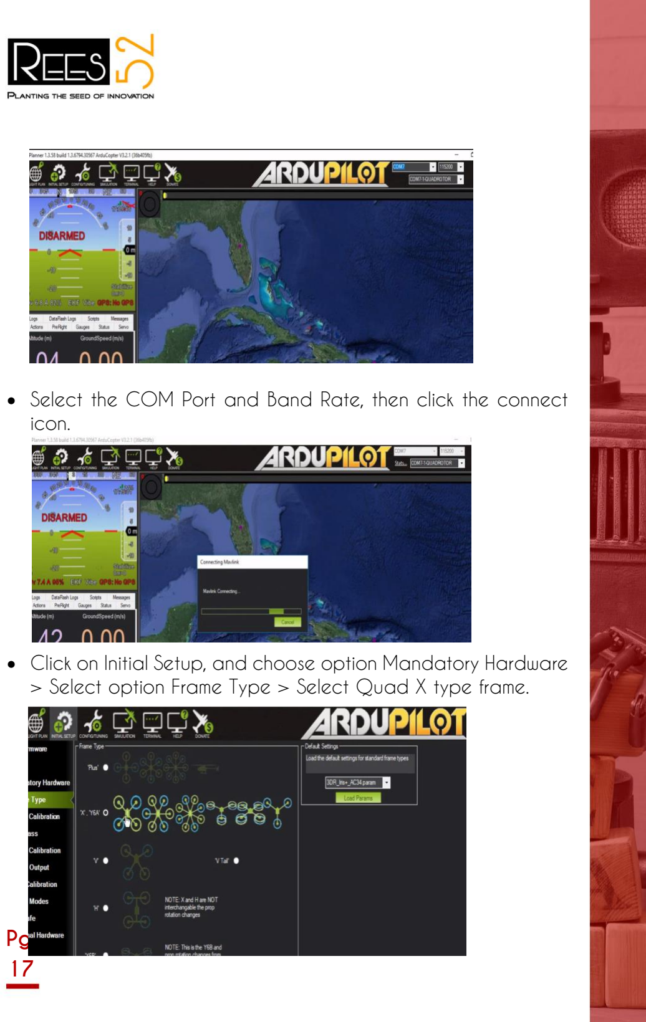
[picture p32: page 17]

Pg
17
- Select the COM Port and Band Rate, then click the connect icon.
- Click on Initial Setup, and choose option Mandatory Hardware > Select option Frame Type > Select Quad X type frame.

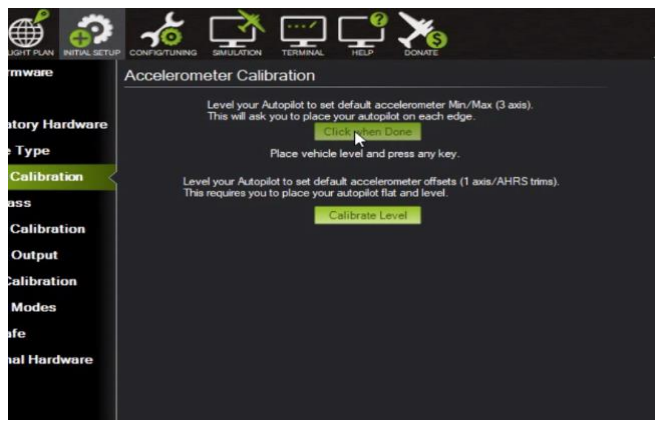
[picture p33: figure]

Pg
18
- Click on Accel Calibration and choose option Calibrate Accel and Follow the given instructions given in the image below.
- Now, Place vehicle (Quadcopter Frame) on its left side and press any key.
- Place vehicle (Quadcopter Frame) on its right side and press any key.

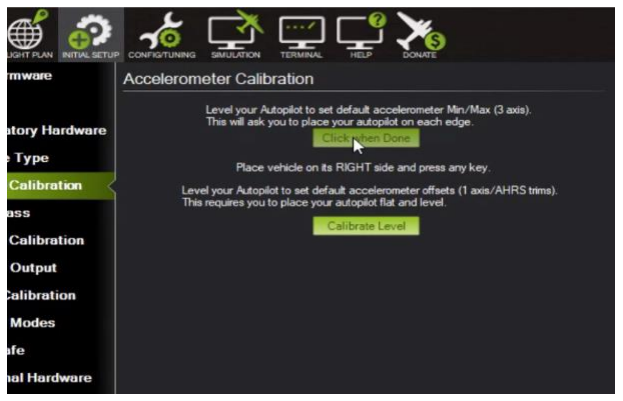
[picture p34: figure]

Pg
19
- Place vehicle (Quadcopter Frame) nose Down & press any key.
- Place vehicle (Quadcopter Frame) nose Up and press any key.

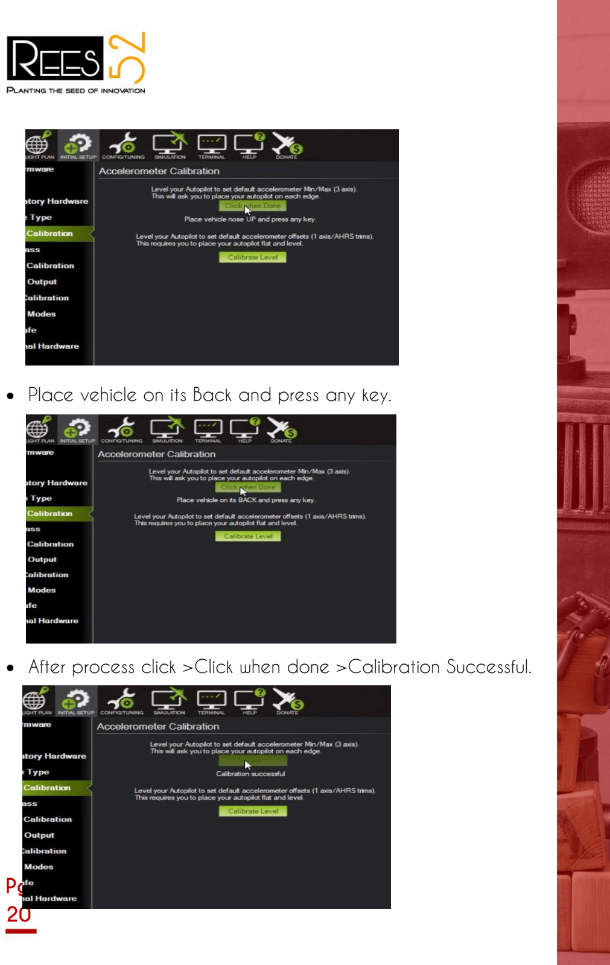
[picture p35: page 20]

Pg
20
- Place vehicle on its Back and press any key.
- After process click >Click when done >Calibration Successful.

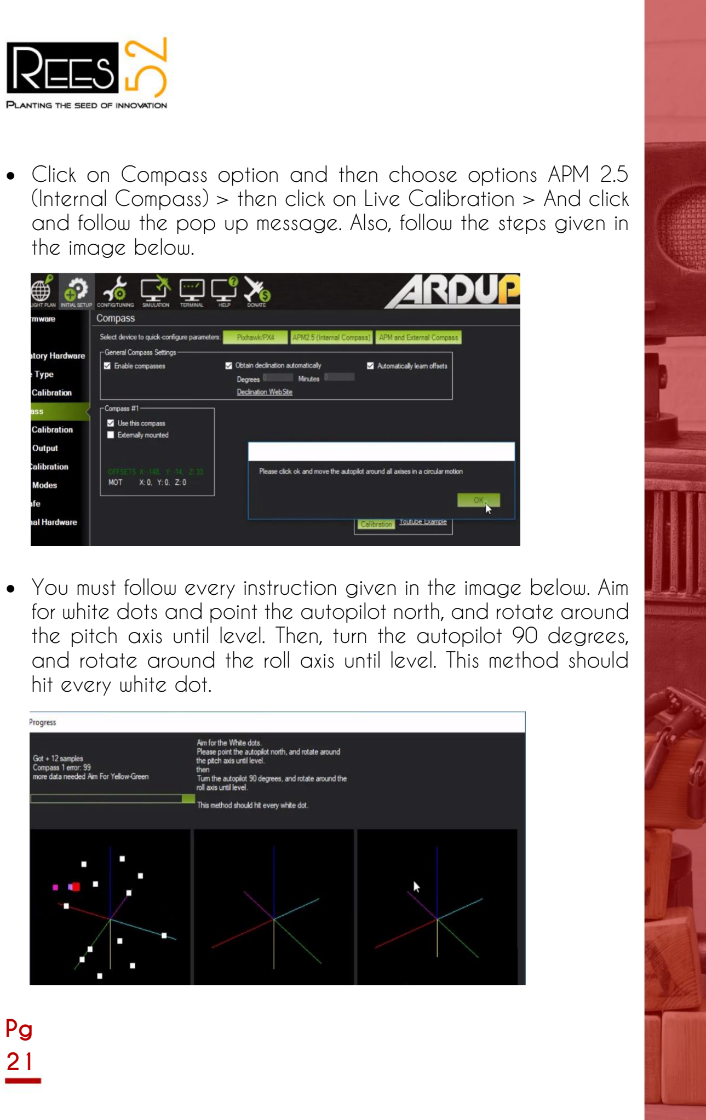
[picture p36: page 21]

Pg
21
- Click on Compass option and then choose options APM 2.5 (Internal Compass) > then click on Live Calibration > And click and follow the pop up message. Also, follow the steps given in the image below.
- You must follow every instruction given in the image below. Aim for white dots and point the autopilot north, and rotate around the pitch axis until level. Then, turn the autopilot 90 degrees, and rotate around the roll axis until level. This method should hit every white dot.


Pg
22
- After successful Live Calibration, new offsets for compass are being saved.
- Click on Radio Calibration > then click on Calibrate Radio option and Check all the buttons whether they are in working condition or not > then click on option Click when done.
- Click OK and move all RC sticks and switches to their extreme positions so the red bars hit the limits.


Pg
23
- Ensure all sticks are centered and throttle is down. Now, click OK button.
- Click on Flight Modes option and follow the instructions as given in the image below. Flight Mode 3 > Click on option At Hold.


Pg
24
- Now, click on Flight Mode 6 > select option Land. And then click on button Save Modes.
- Click on Fail Safe option and click OK button for given Pop up message. Go to Radio > Select option Enabled always RTL. And lastly click on Option Flight Data.

Pg
25
- Now, disconnect the USB cable from the Ardupilot Flight Controller.
- Connect battery with the battery connector of Quadcopter.
- To connect the remote controller, long press the left knob


Pg
26

towards right bottom direction until the red light stops blinking.

- Now, your Quadcopter is ready to Fly.
- Soldering
You should be sure that all your solder joints have the liquid silver look and are reliable. Bad solder joints may cause the FC, RX, ESC or Motor to lose power, prevent the signal from the fc to reach to the ESC or sbus signal from the RX reaching the FC.
- Motor screw length
Take care to use appropriate motor screws depending on the arm thickness, in order to prevent the screws touching the motor windings and damaging the motor. Usually you will receive two sets of motor screws intended for 3mm and 4mm thick arms.
- Proper motor order and rotation

Troubleshooting

Pg
27

Check for proper connection between the ESC signal wires and the flight controller by following the flight controller motor order. When using 4in1 ESC double-check the wire order on the JSD-SH connectors, not all ESC/fc combinations have the same motor order.

- ESC / Motor / Propeller combination
It is worth mentioning that in some cases FPV Drone build problems could be caused by components not matched properly, especially motor / ESC / propeller combination. Some combinations may activate the ESC overload protection or in worst-case scenario cause the motor or the ESC to overheat and burn.

You can also view the tutorial of Quadcopter. The link is given below:

### https://www.youtube.com/watch?v=au0UJruUp4E

Link

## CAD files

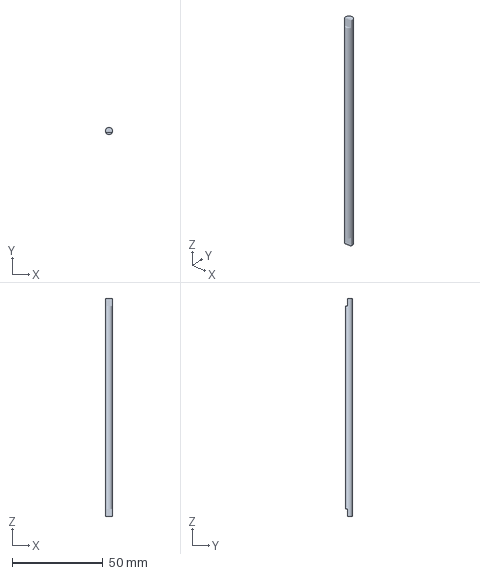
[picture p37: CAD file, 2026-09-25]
GPS_Module.3mf
4.00 x 3.99 x 120.0 mm

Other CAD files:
GPS_Module.STL

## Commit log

2026-09-18 readme soldering
2026-09-25 update 3d file
    [GPS_Module.3mf, GPS_Module.STL]
